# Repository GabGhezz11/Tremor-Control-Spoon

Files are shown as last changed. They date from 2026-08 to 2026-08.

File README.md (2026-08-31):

# Description

An electronic Tremor Control Spoon designed to compensate involuntary hand
tremors in Parkinson's disease patients during meals, developed as part of the
Biodesign course at Università Campus Bio-Medico di Roma in 2023 by a team of 10 students.

---

## Overview

This project focused on the design and development of an electronically
stabilized spoon to assist individuals with Parkinson's disease by compensating
tremors during meal consumption, promoting greater independence and comfort in
daily life. The work was developed in collaboration with a team of colleagues,
with my contribution made remotely while based in Vienna.

The device integrates mechanical, electronic, and control system design:

- **Sensing**: an IMU sensor (MPU-6050) for real-time motion tracking
  (acceleration and angular velocity)
- **Control**: an ATMega328-MUR microcontroller processes sensor data through a
  complementary filter to estimate roll and pitch angles
- **Actuation**: dual servo motors compensate roll and pitch tremors in real
  time, with compensation limited to ±30° on both axes to preserve natural
  eating motion

## Repository Structure

- `firmware/` — Arduino/C firmware implementing the sense-plan-act control loop
  - `TCS_control.ino` — main Arduino sketch
  - `Functions.c` — control and filtering functions
  - `Variables.h` — shared variable/constant definitions
- `electronics/` — PCB design and documentation (Eagle CAD)
  - `scheda_progetto_ver_4.2.sch` — schematic
  - `scheda_progetto_ver_4.2.brd` — board layout
  - `BoM_ver4.2.xlsx` — bill of materials
  - `scheda_progetto_ver_4` — project/design documentation
- `cad/` — Mechanical design files (Solid Edge/STEP) for the handle, motor
  case, and spoon tool
  - `.step Files/` — final STEP files, importable in any CAD software
  - `Drafts/` — intermediate/working Solid Edge design iterations
- `data-analysis/` — MATLAB scripts used to extract tremor frequency and
  acceleration/angular velocity ranges from a reference Parkinsonian tremor
  dataset, informing sensor and motor specifications

## Design Highlights

**Mechanical**: modeled in Solid Edge and based on anthropometric hand data
from adult users, optimized for usability, compactness, and dishwasher-safe
cleaning. Made of polypropylene (biocompatible, heat-resistant, dishwasher-safe)
with silicon caps for the removable USB/charging ports.

**Electronics**: sensing, control, and power supply modules integrated onto a
single miniaturized PCB (57 x 31 mm, a 10% area reduction from the original
demo stripboard), powered by a 2S1P LiPo battery (800 mAh, 7.4 V), with voltage
regulation and USB communication circuits.

**Firmware**: a complementary filter combines accelerometer and gyroscope data
to estimate roll and pitch angles, driving the servos to counteract tremor in
real time while allowing intentional tilting (e.g., to scoop food).

## Personal Contribution - Matlab Data Analysis

The analysis focused on two tremor-related tasks from the reference dataset:

- **Kinetic tremor (task AS316)**: analyzed to extract the acceleration and
  angular velocity ranges during a spoon-eating-like motion.
- **Postural tremor (task AS315)**: analyzed to identify the maximum and
  dominant frequencies of the Parkinsonian tremor signal.

### Scripts

| Script | Purpose |
|---|---|
| `Ranges_acc_v.mlx` | Computes the acceleration and angular velocity **ranges** (kinetic tremor, all 3 subjects, all 3 sensor locations) |
| `Dominant_freq_subj1.mlx` | Computes the **dominant frequency** of acc/gyro signals for Subject 1 (postural tremor) |
| `Dominant_freq_subj2.mlx` | Computes the **dominant frequency** of acc/gyro signals for Subject 2 (postural tremor) |
| `Dominant_freq_subj3.mlx` | Computes the **dominant frequency** of acc/gyro signals for Subject 3 (postural tremor) |
| `Dominant_freq_global.mlx` | Aggregates the dominant-frequency results of all subjects/locations and returns the global maximum |
| `Max_freq_subj1.mlx` | Computes the **maximum frequency** (95% PSD energy threshold) for Subject 1 (postural tremor) |
| `Max_freq_subj2.mlx` | Computes the **maximum frequency** (95% PSD energy threshold) for Subject 2 (postural tremor) |
| `Max_freq_subj3.mlx` | Computes the **maximum frequency** (95% PSD energy threshold) for Subject 3 (postural tremor) |
| `Max_freq_global.mlx` | Aggregates the maximum-frequency results of all subjects/locations and returns the global maximum |
| `createFit.m` | Auto-generated helper (MATLAB Distribution Fitter) used to fit a probability distribution to the angular velocity data — required by `Ranges_acc_v.mlx` |

### Methodology

**1. Signal preprocessing**
- Raw 3-axis accelerometer and gyroscope data are extracted from the dataset (`Subj{i}.off.taskASxxx.<sensor_location>.acc/.gyro`).
- A 4th-order Butterworth **high-pass filter** (cut-off 1 Hz), applied with `filtfilt` (zero-phase), removes gravity/motion bias while preserving tremor content.
- The 3-axis signals are combined into a single magnitude signal via the Euclidean norm (vector module).

**2. Frequency-domain analysis (postural tremor)**
- The **Power Spectral Density (PSD)** of the filtered signal is estimated with `periodogram`.
- **Dominant frequency**: frequency corresponding to the PSD peak.
- **Maximum frequency**: frequency below which 95% of the cumulative PSD energy is contained (computed via `trapz` on the PSD curve).
- Both metrics are computed per subject, per sensor location (index, thumb, metacarpus), and per signal type (acceleration, angular velocity), then aggregated across subjects to obtain the **global maximum/dominant frequency**, used to define the minimum IMU sampling rate (Nyquist criterion).

**3. Amplitude analysis (kinetic tremor)**
- Acceleration and angular velocity magnitudes are pooled across all subjects and sensor locations.
- A **kernel density estimate** (`ksdensity`, positive support) is computed for both signals.
- The upper bound of the working range is defined as the value below which 95% of the cumulative probability density falls; the range is then obtained by mirroring this value onto the negative axis (assuming symmetric bidirectional motion).
- The result is cross-checked against the 95th percentile/quantile of the raw pooled data (`quantile`, `prctile`) as a validation step.
- `createFit.m` is used to verify that the angular velocity distribution is **not normal**, justifying the use of the empirical (KDE-based) approach instead of a parametric one.

### Outputs used for hardware design
- **Acceleration range** → used to select the IMU accelerometer full-scale range.
- **Angular velocity range** → used to select the IMU gyroscope full-scale range.
- **Global maximum/dominant frequency** → used to define the minimum IMU sampling rate (via Nyquist criterion) and to size the servo motor bandwidth/response requirements.

Results informed the electronic design directly: a maximum signal frequency of 42 Hz and dominant frequency of 12.3 Hz were used to set the IMU sampling rate
(respecting the Nyquist theorem), while the acceleration range (±1.32 g) and angular velocity range (±4.91 rad/s) informed the sensor configuration.

## Key Results

- Compensates roll and pitch within ±30° on both axes
- Total weight: 133.4 g (spoon: 81 g)
- Overall length: 200 mm, comparable to a standard spoon
- Production cost: €69.28 (under the €100 target)
- Self-evaluation score: 34/40 across washability, safety, ergonomics and marketability criteria

## How to Use This Repository

- To review the firmware logic, see `firmware/TCS_control.ino`
- To inspect the PCB design, open the Eagle files (`.sch`/`.brd`) in `electronics/`
- To view the mechanical design, open the `.step` files inside `cad/.step Files/`
- To reproduce the tremor data analysis, open the MATLAB scripts in `data-analysis/`

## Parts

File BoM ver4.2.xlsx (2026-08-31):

Quantity | Value | Package | Order code | Manufacturer | Manuf. Code | Availability | Price (from) | Description
2 | 4,7uF_16V | TAN-A | 2333019 | KYOCERA AVX | TAJA475M016RNJ | 3195 | 0.094 | KYOCERA AVX - TAJA475M016RNJ - Condensatore al tantalio SMT, 4.7 µF, 16 V, 1206 [3216 metrico], ± 20%, 4 ohm, A
5 | 1uF | C0603 | 3340859 | KYOCERA AVX | 0603YC105KAT4A | 11449 | 0.034 | KYOCERA AVX - 0603YC105KAT4A - Condensatore ceramico multistrato SMD, 1 µF, 16 V, 0603 [1608 metrico], ± 10%, X7R
5 | 0.1 uF | C0603 | 2904649 | KEMET | C0603C104K3RECTU | 1830 | 0.028 | KEMET - C0603C104K3RECTU - Condensatore ceramico multistrato SMD, ESD, 0.1 µF, 25 V, 0603 [1608 metrico], ± 10%, X7R
1 | 0.01 uF | C0603 | 2456107 | MURATA | GRM1885C1H103JA01D | 29047 | 0.08 | MURATA - GRM1885C1H103JA01D - CON. 0.01µF, 50V, 5%, C0G/NP0, 0603
1 | 2200 pF | C0603 | 2534028 | WURTH ELEKTRONIK | 885012206061 | 1965 | 0.0103 | WURTH ELEKTRONIK - 885012206061 - Condensatore ceramico multistrato SMD, 2200 pF, 25 V, 0603 [1608 metrico], ± 10%, X7R, WCAP-CSGP
1 | SS1P3L | DO220AAL | 2889242 | VISHAY | SS1P3L-M3/84A | 2550 | 0.108 | VISHAY - SS1P3L-M3/84A - Raddrizzatore Schottky, 30 V, 1.5 A, singolo, DO-220AA, 2 Pin, 450 mV
1 | MFFSMF050 | 0603-1608X90N | 1717227 | BOURNS | MF-FSMF050X-2 | 7337 | 0.336 | BOURNS - MF-FSMF050X-2 - Fusibile ripristinabile PPTC, 0603 (1608 metrico), MF-FSMF, 6 VDC, 500 mA, 1 A, 0.1 s
1 | FT232RL | SSOP28 | 895-FT232RL (Mouser) | FTDI | FT232RL-REEL | 32097 | 4.46 | CI di interfaccia USB USB to Serial UART Enhanced IC SSOP-28
1 | LM1117IMPX-5.0 | LINEAR_SOT223 | 926-LM1117IMPX50NOPB (Mouser) | TEXAS INSTRUMENTS | LM1117IMPX-5.0/NOPB | 19786 | 1.26 | Regolatori di tensione LDO 800mA LDO Linear Reg
1 | 328P-MUR | VQFN32 | 2425125 | MICROCHIP | ATMEGA328P-MUR | 45330 | 2.44 | MICROCHIP - ATMEGA328P-MUR - MCU a 8 bit, bassa potenza, alte prestazioni, AVR ATmega Family ATmega328 Series Microcontrollers
1 | MCP73213T-A6AI_MF | SON50P300X300X100-11N | 579-MCP73213TA6AIMF (Mouser) | MICROCHIP | MCP73213T-A6AI/MF | 1546 | 2.24 | Gestione batterie OVP BATTERY CHARGER DUAL CELL
1 | 694106105102 | CONN3_06105102_WRE | 2472147 | WURTH ELEKTRONIK | 694106105102 | 272 | 1.08 | WURTH ELEKTRONIK - 694106105102 - Connettore di alimentazione DC, femmina, 5 A, 2 mm, montaggio superficiale (SMT)
1 | 67503-1020 | 675031020 | 1125348 | MOLEX | 67503-1020... | 7498 | 0.773 | MOLEX - 67503-1020... - Connettore USB, mini USB tipo B, USB 2.0, femmina, 5 Vie, montaggio superficiale (SMT)
1 |  | 1X02 | 3398291 | AMP - TE CONNECTIVITY | 171826-2 | 7110 | 0.178 | AMP - TE CONNECTIVITY - 171826-2 - Connettore a strip maschio, R/A, filo-scheda, 2.5 mm, 1 File, 2 Contatti
1 |  | 2X03 | 3049596 | MOLEX | 87911-0611 | 471 | 0.507 | MOLEX - 87911-0611 - Connettore a strip maschio, scheda a scheda, 2.54 mm, 2 File, 6 Contatti
2 | Green | CHIPLED_0805 | 2099239 | KINGBRIGHT | KPT-2012SGC | 15562 | 0.0824 | KINGBRIGHT - KPT-2012SGC - LED, bassa potenza, verde, SMD, 0805 [2012 metrico], 20 mA, 2.2 V, 568 nm
2 | 4.7 KΩ | R0603 | 3495312 | YAGEO | AC0603JR-074K7L | 3289 | 0.0028 | YAGEO - AC0603JR-074K7L - Resistore a chip SMD, 4.7 kohm, ± 5%, 100 mW, 0603 [1608 metrico], film spesso
5 | 1K | R0603 | 1770133 | BOURNS | CAY16-102J4LF | 22350 | 0.0176 | BOURNS - CAY16-102J4LF - Resistore di rete fisso, 1 kohm, Isolato, 4 Resistors, 1206 [3216 metrico], Convessi, ± 5%
1 | 3K | R0603 | 2908368 | BOURNS | CR0603-JW-302ELF | 76925 | 0.0018 | BOURNS - CR0603-JW-302ELF - Resistore a chip SMD, 3 kohm, ± 5%, 100 mW, 0603 [1608 metrico], film spesso, per scopi generici
1 | RESET | SMD_157SW | 653-B3U-1000P (Mouser) | OMRON ELECTRONICS INC. | B3U-1000P | 45797 | 0.94 | Interruttore tattile SPST-NO Ad azionamento dall'alto A montaggio superficiale
1 | MFS201N-16-Z | MFS201N-16-Z_NDC | 2854845 | NIDEC COMPONENTS | MFS201N-16-Z | 14 | 1.3 | NIDEC COMPONENTS - MFS201N-16-Z - Interruttore a slitta, superminiaturizzato, DPDT, On-On, foro passante (THT), MFS, 1 A, 125 V
1 | MPU-6050 | QFN50P400X400X95-24N | 410-MPU-6050 (Mouser) | TDK INVENSENSE | MPU-6050 | 21433 | 7.94 | TDK INVENSENSE - MPU-6050 - Modulo MEMS, serie MotionTracking, giroscopio/accelerometro triassiale, ±16g, 2,375V-3,46V, QFN-24
1 | 16MHz | RESONATOR | 81-CSTNE16M0VH3L000R (Mouser) | MURATA | CSTNE16M0VH3L000R0 | 60201 | 0.344 | Risonatori 16.0 MHZ 15PF

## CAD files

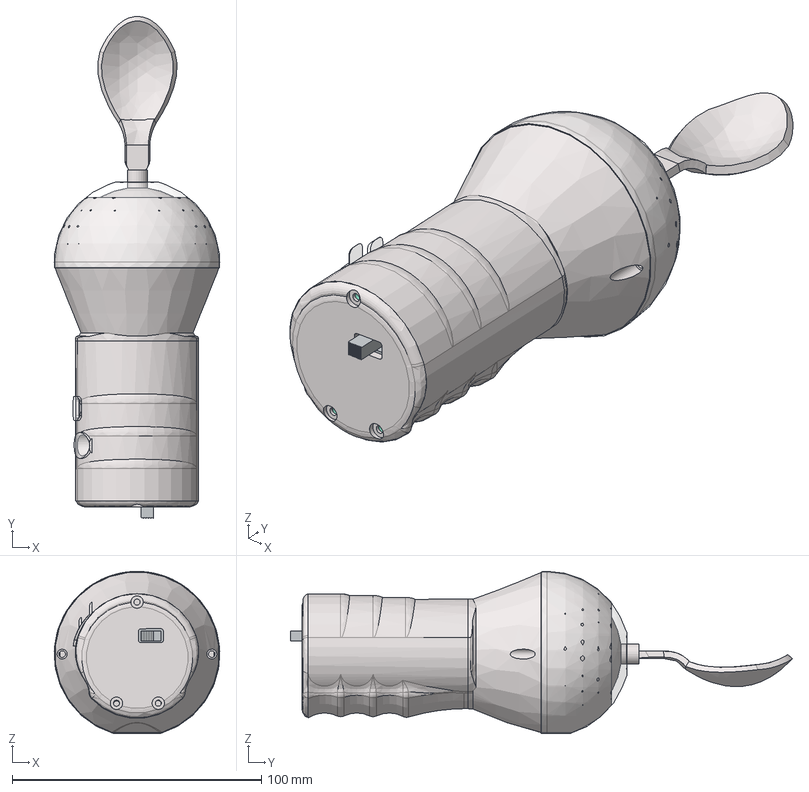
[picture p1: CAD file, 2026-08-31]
Spoon_Asm.stp
66.4 x 201.3 x 65.1 mm
HandleA
Scheda
Batteria
HandleR
CaseServi
Supporto1
Supporto2
Tool
HD1370A x 2
CaseServi2
Membrana
TappoAC
TappoUSB

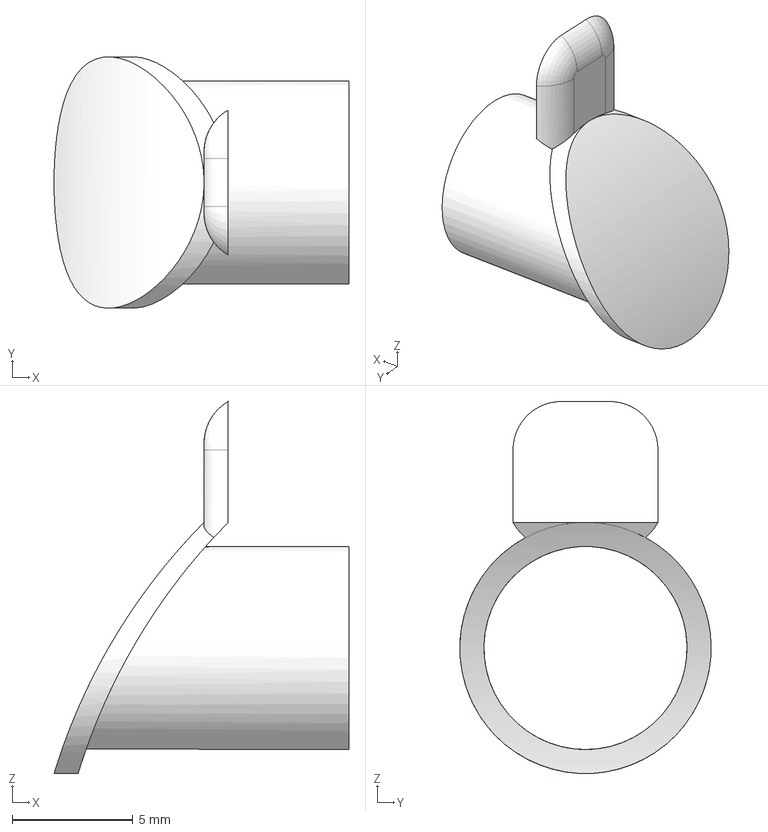
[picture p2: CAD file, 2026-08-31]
CapAC.stp
12.2 x 10.4 x 15.4 mm

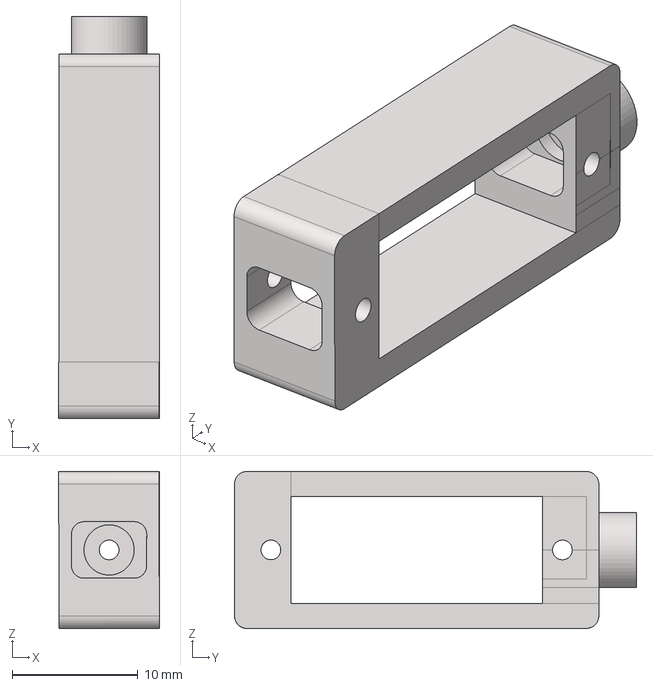
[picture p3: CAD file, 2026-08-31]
Support1.stp
8.01 x 32.0 x 12.5 mm

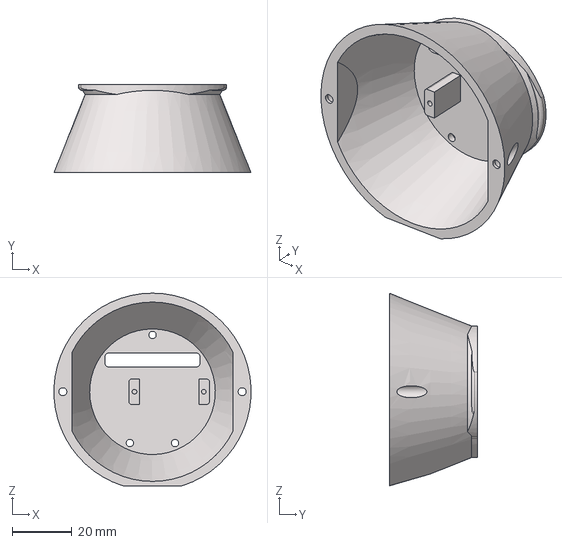
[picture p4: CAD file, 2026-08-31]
CaseServos.stp
65.9 x 29.5 x 64.5 mm

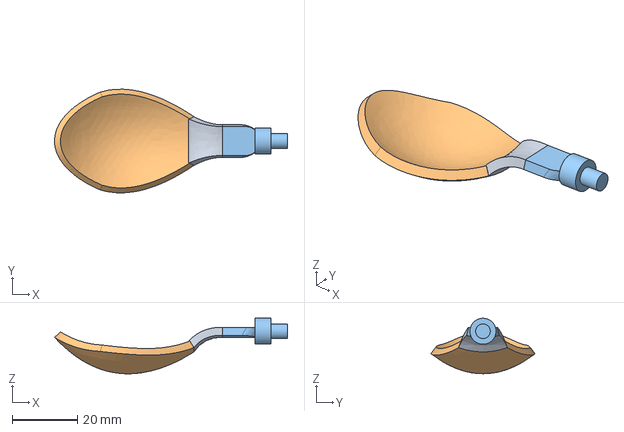
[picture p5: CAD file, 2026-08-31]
Tool.stp
71.6 x 31.8 x 17.1 mm

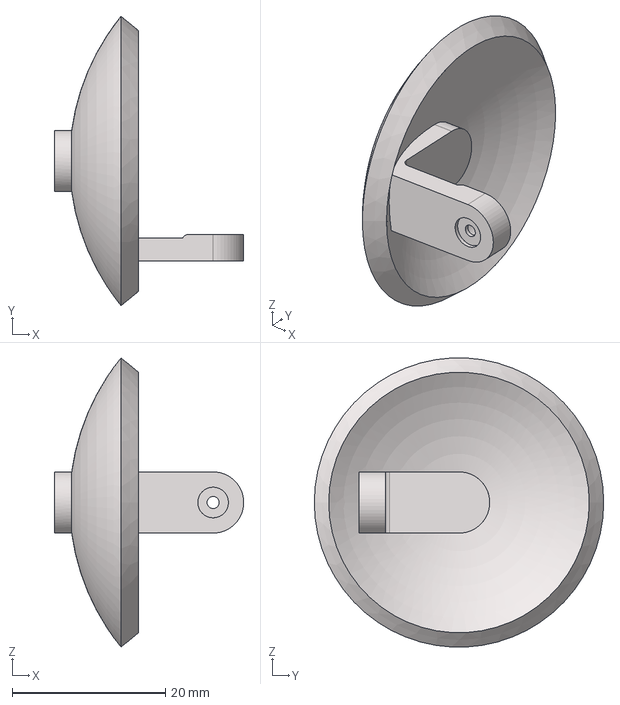
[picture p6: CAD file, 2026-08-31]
Support2.stp
24.7 x 37.8 x 37.7 mm

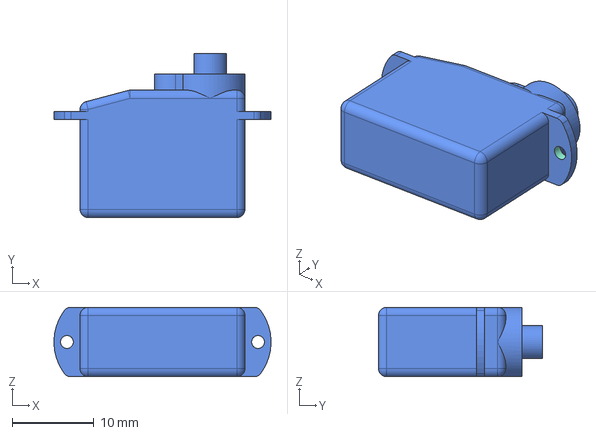
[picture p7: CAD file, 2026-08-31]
HD1370A.stp
26.6 x 20.1 x 8.50 mm

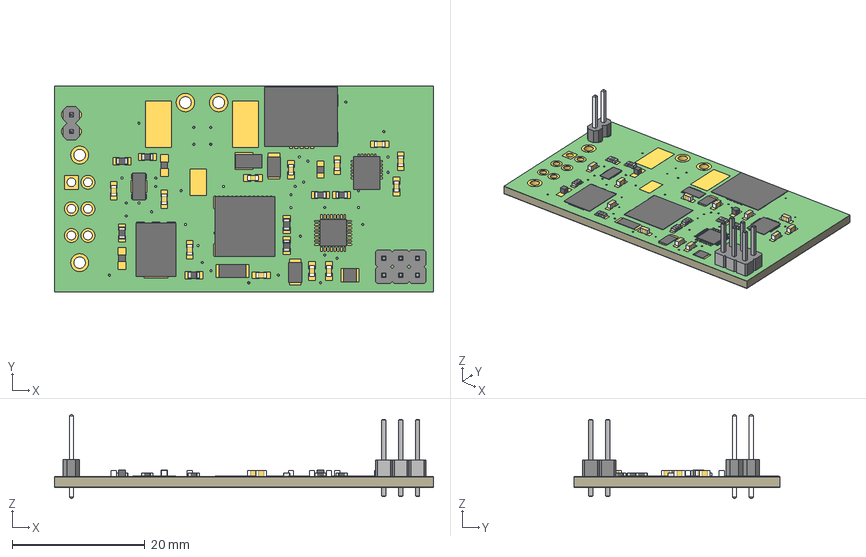
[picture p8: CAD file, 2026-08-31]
PCBFusion.step
57.0 x 31.0 x 12.6 mm
Scheda
1-copper
16-copper
1-soldermask
16-soldermask
0603-1608X90N
VQFN32
TAN-A x 2
USB-MINI-B_2
RESONATOR
DO220AAL
LINEAR_SOT223
SSOP28
SON50P300X300X100-11N
QFN50P400X400X95-24N
CHIPLED_0805 x 2
SMD_157SW
1X02
2X03
C0603 x 12
R0603 x 8

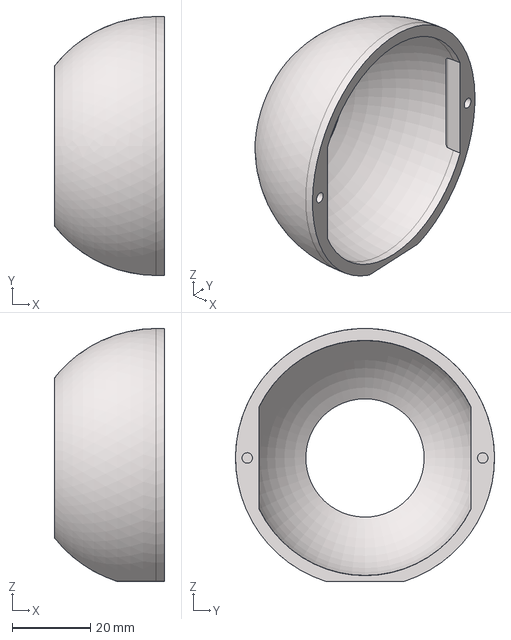
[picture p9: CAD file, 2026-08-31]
CaseServos2.stp
28.1 x 66.0 x 64.5 mm

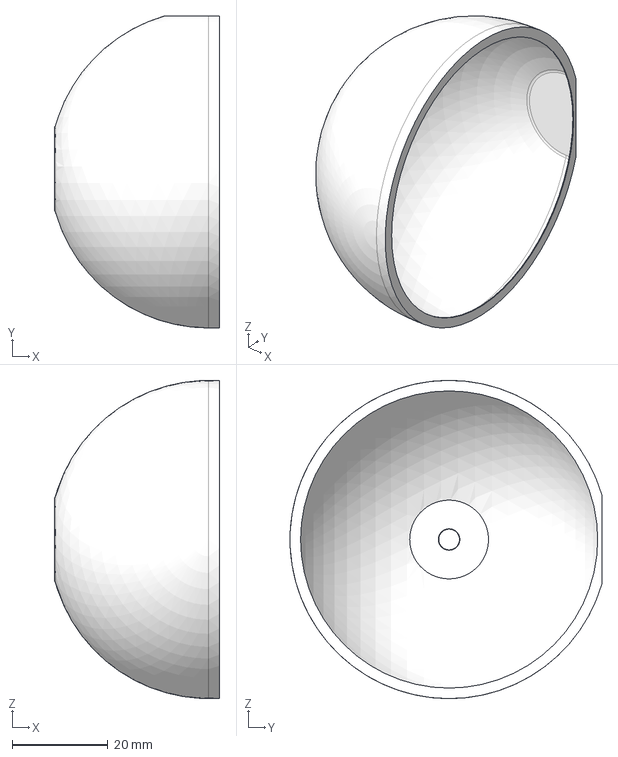
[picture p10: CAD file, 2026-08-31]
Film.stp
34.5 x 65.1 x 66.4 mm

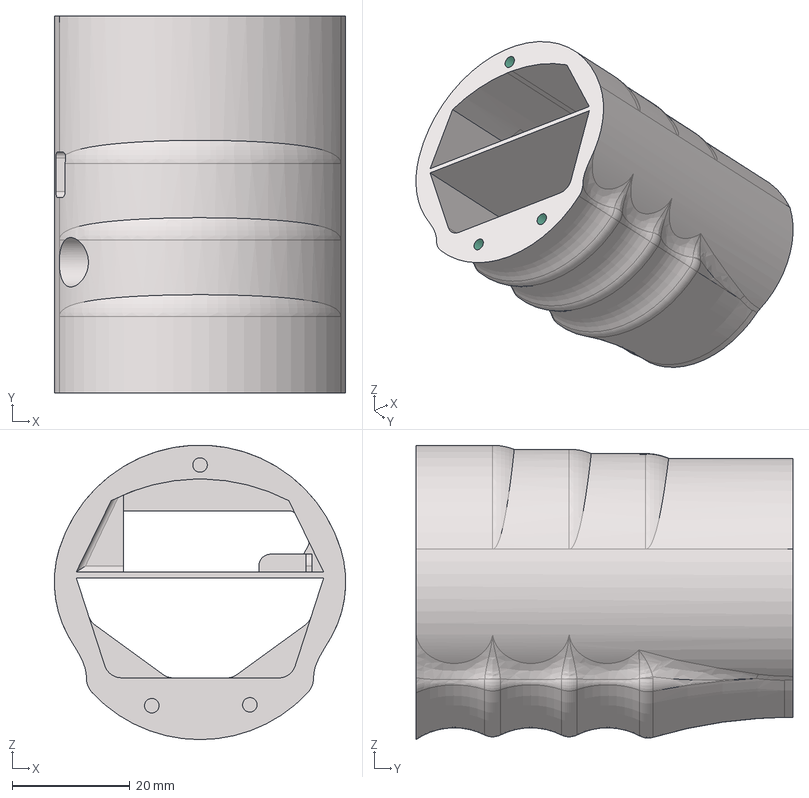
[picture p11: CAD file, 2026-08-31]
HandleA.stp
49.4 x 64.0 x 50.0 mm

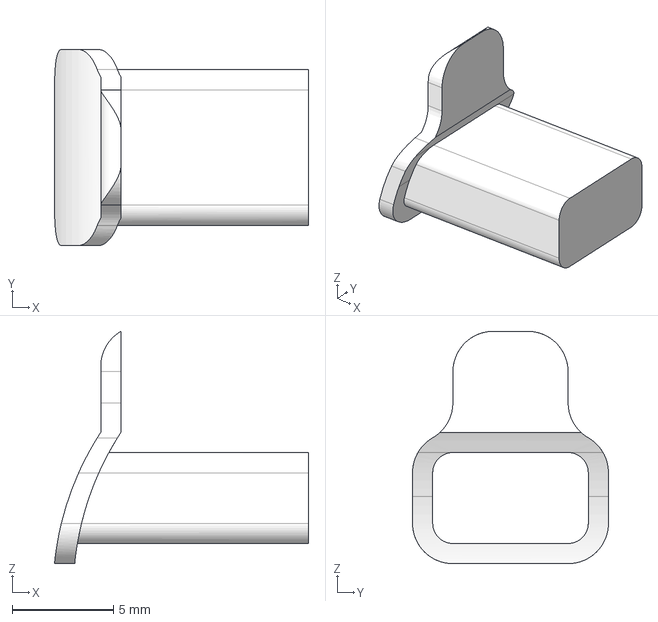
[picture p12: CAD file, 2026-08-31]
CapUSB.stp
12.6 x 9.70 x 11.5 mm

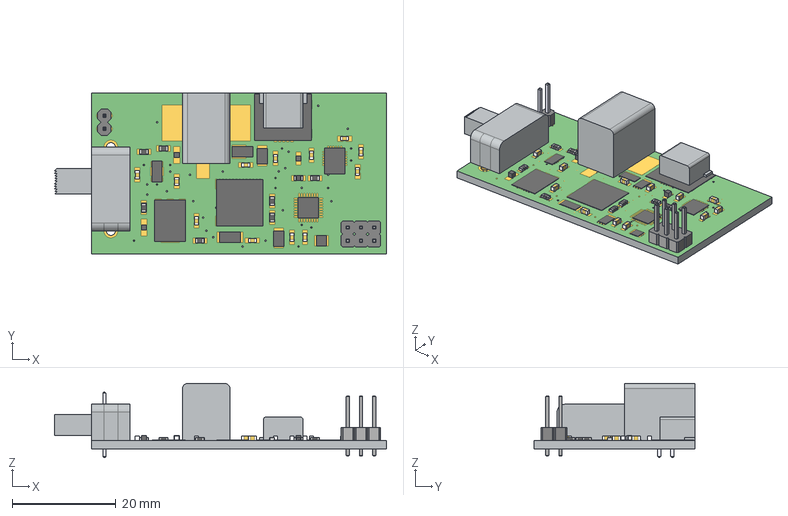
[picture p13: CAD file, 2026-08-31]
PCB.stp
64.1 x 31.0 x 14.3 mm

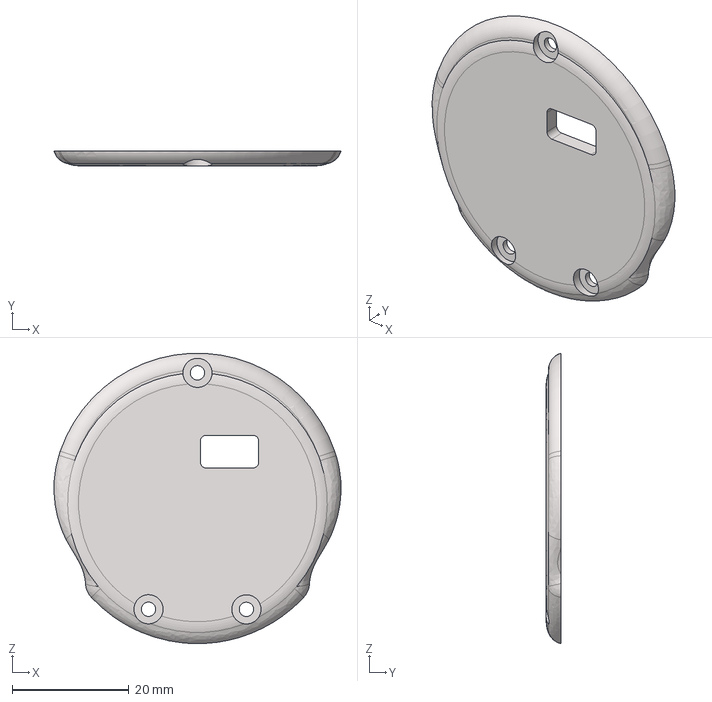
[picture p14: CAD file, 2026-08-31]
HandleR.stp
49.2 x 2.50 x 49.7 mm

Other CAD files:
Battery.stp

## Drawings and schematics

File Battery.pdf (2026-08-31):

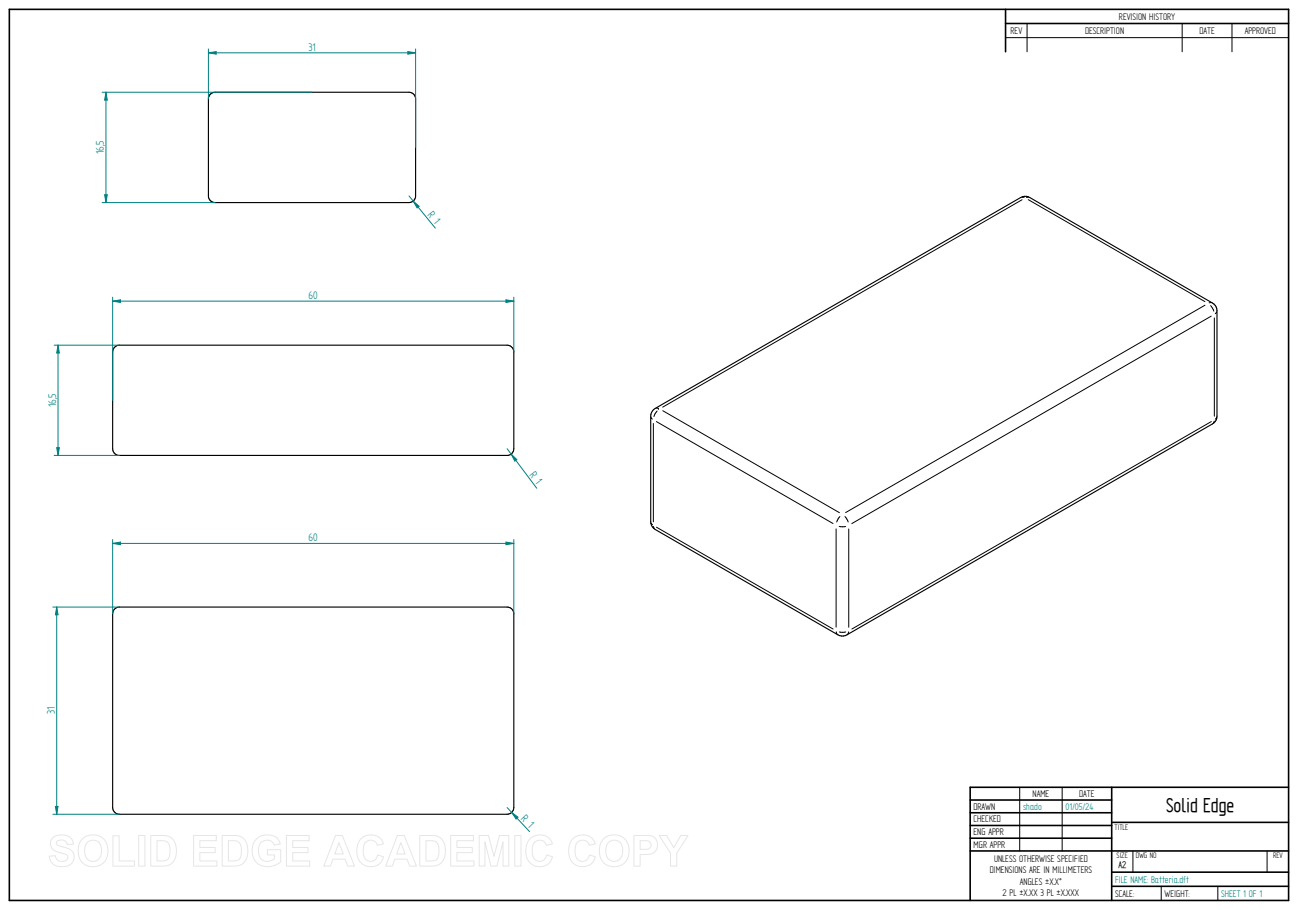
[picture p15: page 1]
TITLE; SCALE:; WEIGHT:; SHEET 1 OF 1

31 | REVISION HISTORY

REV | DESCRIPTION | DATE | APPROVED

NAME | DATE | Solid Edge

DRAWN | shado | 01/05/24
CHECKED
ENG APPR
MGR APPR
UNLESS OTHERWISE SPECIFIED DIMENSIONS ARE IN MILLIMETERS ANGLES ±X.X° 2 PL ±X.XX 3 PL ±X.XXX | SIZE A2 | DWG NO | REV

FILE NAME: Batteria.dft

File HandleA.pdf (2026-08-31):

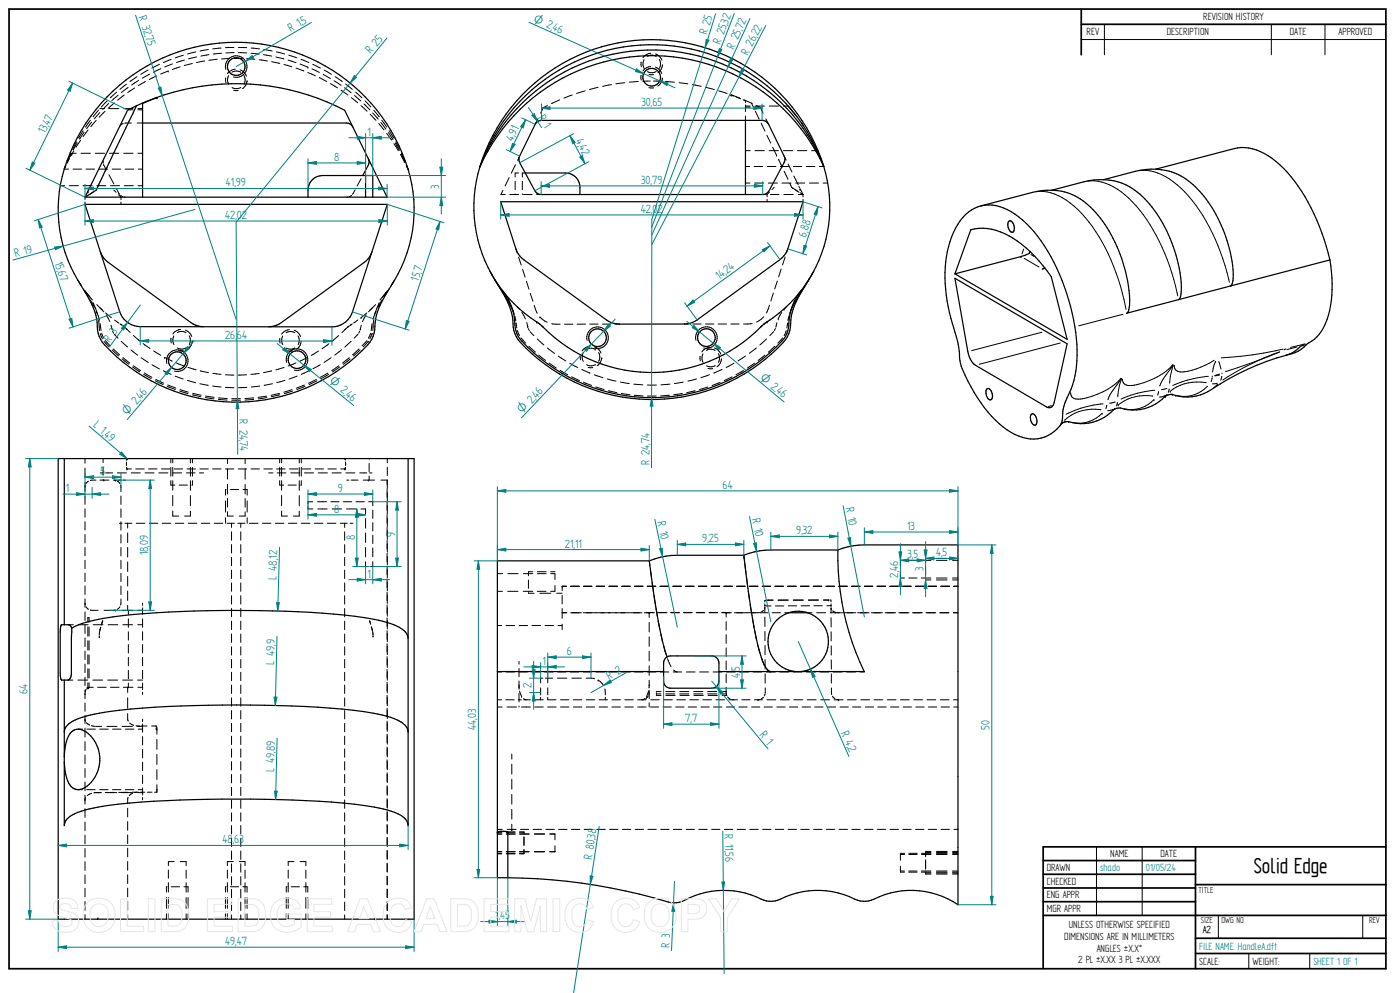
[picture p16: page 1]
ENG APPR; TITLE; SCALE:; WEIGHT:; SHEET 1 OF 1

REVISION HISTORY

REV | DESCRIPTION | DATE | APPROVED

NAME | DATE | Solid Edge

DRAWN | shado | 01/05/24
CHECKED

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

FILE NAME: HandleA.dft

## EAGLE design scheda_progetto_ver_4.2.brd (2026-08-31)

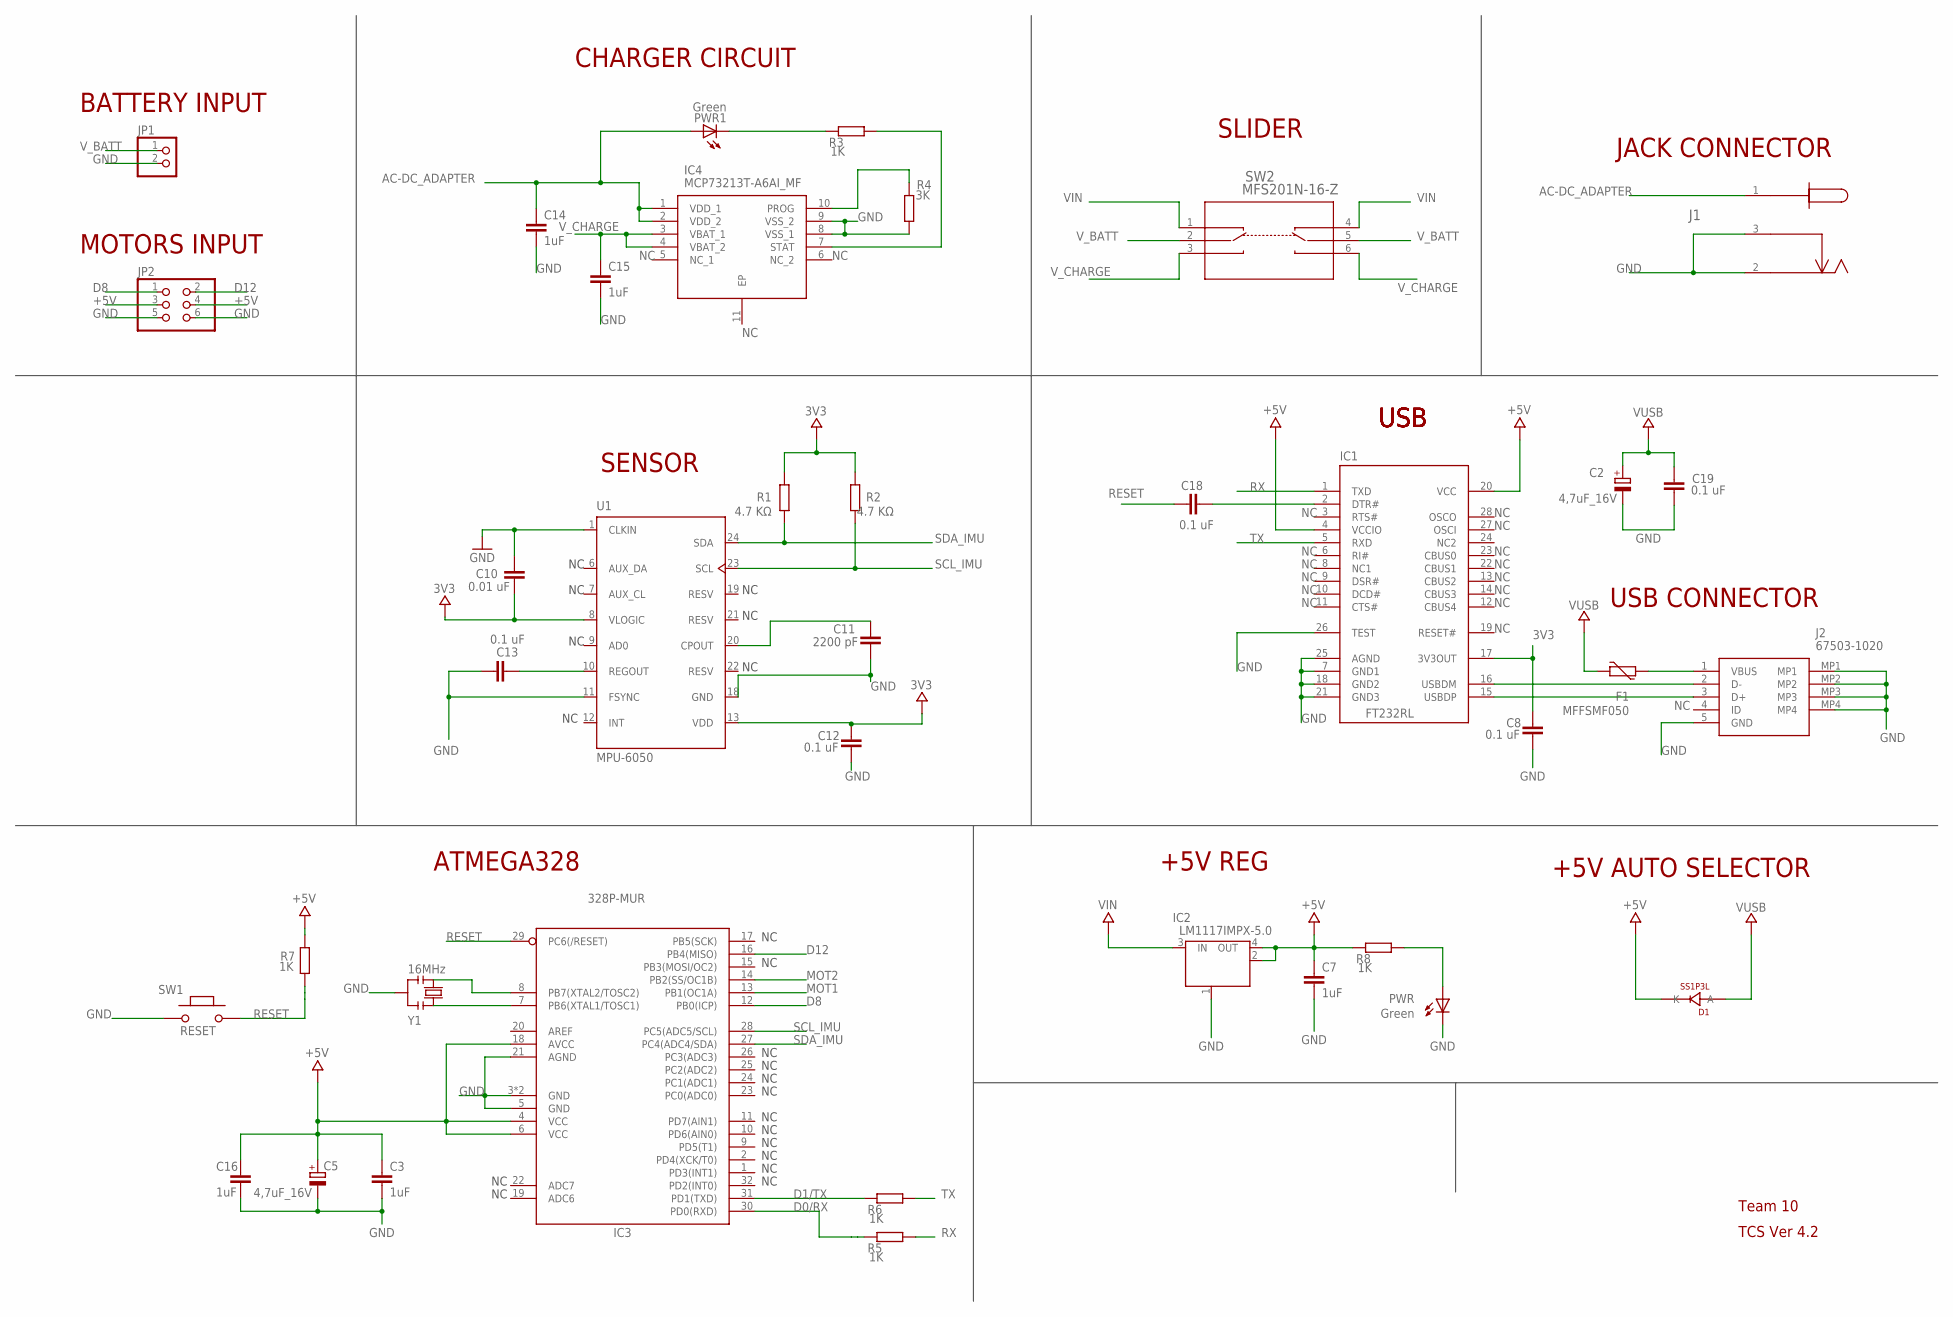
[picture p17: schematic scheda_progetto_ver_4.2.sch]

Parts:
C2, C5: 4,7uF_16V; TAN-A; MPN TAJA475M016RNJ
C3, C7, C14, C15, C16: 1uF; C0603; MPN 0603YC105KAT4A
C8, C12, C13, C18, C19: 0.1 uF; C0603; MPN C0603C104K3RECTU
C10: 0.01 uF; C0603; MPN GRM1885C1H103JA01D
C11: 2200 pF; C0603; MPN 885012206061
D1: SS1P3L; DO220AAL; MPN SS1P3L-M3/84A
F1: MFFSMF050; 0603-1608X90N; MPN MF-FSMF050X-2
IC1: FT232RL; SSOP28
IC2: LM1117IMPX-5.0; LINEAR_SOT223
IC3: 328P-MUR; VQFN32; MPN ATMEGA328P-MUR
IC4: MCP73213T-A6AI_MF; SON50P300X300X100-11N
J1: 694106105102; CONN3_06105102_WRE; MPN 694106105102
J2: 67503-1020; 675031020; MPN 67503-1020...
JP1: PINHD-1X2; 1X02; MPN 171826-2
JP2: PINHD-2X3; 2X03; MPN 87911-0611
PWR, PWR1: Green; CHIPLED_0805; MPN KPT-2012SGC
R1, R2: 4.7 KΩ; R0603; MPN AC0603JR-074K7L
R3, R5, R6, R7, R8: 1K; R0603; MPN CAY16-102J4LF
R4: 3K; R0603; MPN CR0603-JW-302ELF
SW1: RESET; SMD_157SW; MPN R13-24AL-05-BB
SW2: MFS201N-16-Z; MFS201N-16-Z_NDC; MPN MFS201N-16-Z
U1: MPU-6050; QFN50P400X400X95-24N; MPN MPU-6050
Y1: 16MHz; RESONATOR

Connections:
3V3: C8.2, C10.1, C12.2, IC1.17 (3V3OUT), R1.2, R2.2, U1.8 (VLOGIC), U1.13 (VDD)
+5V: C3.1, C5.1 (+), C7.1, C16.1, D1.P$1 (K), IC1.4 (VCCIO), IC1.20 (VCC), IC2.2 (OUT), IC2.4 (OUT), IC3.4 (VCC), IC3.6 (VCC), IC3.18 (AVCC), JP2.3, JP2.4, R7.2, R8.1
AC-DC_ADAPTER: C14.1, IC4.1 (VDD_1), IC4.2 (VDD_2), J1.1, PWR1.A
D0/RX: IC3.30 (PD0(RXD)), R5.1
D1/TX: IC3.31 (PD1(TXD)), R6.1
D8: IC3.12 (PB0(ICP)), JP2.1
D12: IC3.16 (PB4(MISO)), JP2.2
GND: C2.2 (-), C3.2, C5.2 (-), C7.2, C8.1, C10.2, C11.1, C12.1, C13.2, C14.2, C15.2, C16.2, C19.1, IC1.7 (GND1), IC1.18 (GND2), IC1.21 (GND3), IC1.25 (AGND), IC1.26 (TEST), IC2.1 (GND/ADJ), IC3.3 (GND), IC3.5 (GND), IC3.21 (AGND), IC3.33 (GND), IC4.8 (VSS_1), IC4.9 (VSS_2), J1.2, J1.3, J2.5 (GND), J2.MP1, J2.MP2, J2.MP3, J2.MP4, JP1.2, JP2.5, JP2.6, PWR.C, R4.2, SW1.1, U1.1 (CLKIN), U1.11 (FSYNC), U1.18 (GND), Y1.2
MOT1: IC3.13 (PB1(OC1A))
MOT2: IC3.14 (PB2(SS/OC1B))
unnamed: IC3.8 (PB7(XTAL2/TOSC2)), Y1.3
unnamed: IC3.7 (PB6(XTAL1/TOSC1)), Y1.1
unnamed: PWR.A, R8.2
unnamed: C18.1, IC1.2 (DTR#)
unnamed: IC1.15 (USBDP), J2.3 (D+)
unnamed: IC1.16 (USBDM), J2.2 (D-)
unnamed: C11.2, U1.20 (CPOUT)
unnamed: IC4.10 (PROG), R4.1
unnamed: PWR1.C, R3.1
unnamed: IC4.7 (STAT), R3.2
unnamed: C13.1, U1.10 (REGOUT)
unnamed: F1.2, J2.1 (VBUS)
RESET: C18.2, IC3.29 (PC6(/RESET)), R7.1, SW1.2
RX: IC1.1 (TXD), R5.2
SCL_IMU: IC3.28 (PC5(ADC5/SCL)), R2.1, U1.23 (SCL)
SDA_IMU: IC3.27 (PC4(ADC4/SDA)), R1.1, U1.24 (SDA)
TX: IC1.5 (RXD), R6.2
VIN: IC2.3 (IN), SW2.1, SW2.4
VUSB: C2.1 (+), C19.2, D1.P$2 (A), F1.1
V_BATT: JP1.1, SW2.2, SW2.5
V_CHARGE: C15.1, IC4.3 (VBAT_1), IC4.4 (VBAT_2), SW2.3, SW2.6

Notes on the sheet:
SENSOR
BATTERY INPUT
MOTORS INPUT
CHARGER CIRCUIT
JACK CONNECTOR
SLIDER
USB
USB CONNECTOR
+5V REG
+5V AUTO SELECTOR
Team 10
TCS Ver 4.2
ATMEGA328

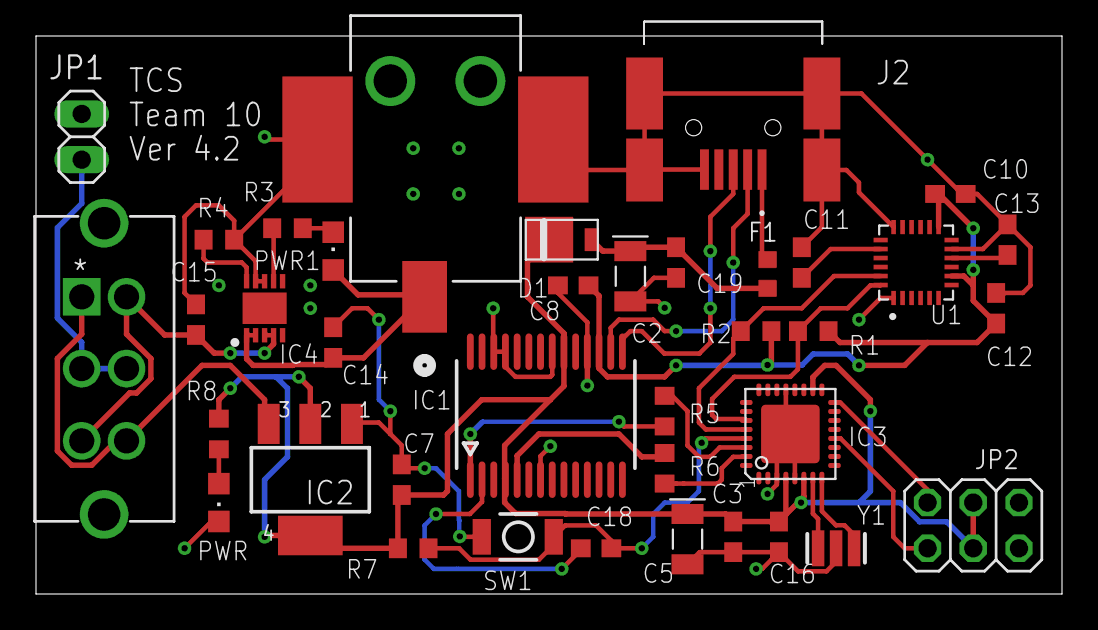
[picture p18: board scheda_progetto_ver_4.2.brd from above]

Board: 2 copper layers, 57.0 x 31.0 mm, 38 parts (0 on the bottom side), 29 nets.

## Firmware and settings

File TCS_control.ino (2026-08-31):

#include "Functions.c"
#include <Wire.h>

// Global variables
const int MPU = 0x68; // MPU6050 I2C address (pag 45 datasheet)
float acc_X, acc_Y, acc_Z; // acceleration
float gyro_X, gyro_Y, gyro_Z, gyro_XOffset, gyro_YOffset, gyro_ZOffset, gyro_X_cal, gyro_Y_cal, gyro_Z_cal; // angular velocity before and after calibration and offset
float phi = 0; // angle x axis (ROLL)
float theta = 0; // angle y axis (PITCH)
float phi_acc, theta_acc, phi_prec, theta_prec; // variables for the implementation of the complementary filter
float square_sum1;
float rad_to_deg = 180 / 3.141592654; // to convert from rad to deg
float fs = 99.5; // sampling frequency
float T = 1.0 / fs; // sampling period

void setup() {

  pinMode(motor1,OUTPUT);
  pinMode(motor2,OUTPUT);

  Serial.begin(2000000); // serial initialization
  init_MPU(); // MPU6050 initialization
  
  position90Deg(); // motors at 90°
  
  calibration(); // sensor calibration

  // Interrupt Setup
  TCCR1A = 0; // set entire TCCR1A register to 0
  TCCR1B = 0; // set entire TCCR1B register to 0
  TCCR1B |= (1 << WGM12); // CTC mode
  TCCR1B |= (1 << CS12) | (1 << CS10); // prescaler 1024
  TCNT1  = 0; // Initialize counter value to 0
  OCR1A = 156; // set OCR1A Register to 156
  TIMSK1 |= (1 << OCIE1A); // Set interrupt on OCR1A

  interrupts(); // Enable Interrupt

}

void loop() {

}

ISR(TIMER1_COMPA_vect) { // ISR associated to timer 1 through COMPA register
  
  interrupts();
  
  readFrom_MPU(); // read from sensor

  noInterrupts(); // disable interrupts

  // Subtraction of the offset
  gyro_X_cal = gyro_X - gyro_XOffset;
  gyro_Y_cal = gyro_Y - gyro_YOffset;
  gyro_Z_cal = gyro_Z - gyro_ZOffset;

  //Complementary Filter
  phi_prec = phi;
  theta_prec = theta;
  square_sum1 = sqrt((acc_Y * acc_Y) + (acc_Z * acc_Z));
  phi_acc = atan2(acc_Y, acc_Z);
  theta_acc = atan2(-acc_X, square_sum1);

  // values of coefficient found from literature
  phi = 0.04 * phi_acc * rad_to_deg + 0.96 * (gyro_X_cal * T + phi_prec);
  theta = 0.04 * theta_acc * rad_to_deg + 0.96 * (gyro_Y_cal * T + theta_prec);

  // Rotation of the motors with limit of +/-30°
  if (theta >= 30 && phi >= 30) {
    // do nothing
  }
  else if (theta >= 30) {
    MP1 = stoppedMotor();
    MP2 = rotationParameters(90 + phi_prec, 90 + phi);
    // Servo commands
    rotateMotors(MP1, MP2);
  }
  else if (phi >= 30) {
    MP1 = rotationParameters(90 + theta_prec, 90 + theta);
    MP2 = stoppedMotor();
    // Servo commands
    rotateMotors(MP1, MP2);
  }
  else if (theta <= -30 && phi <= -30) {
    // do nothing
  }
  else if (theta <= -30) {
    MP1 = stoppedMotor();
    MP2 = rotationParameters(90 + phi_prec, 90 + phi);
    // Servo commands
    rotateMotors(MP1, MP2);
  }
  else if (phi <= -30) {
    MP1 = rotationParameters(90 + theta_prec, 90 + theta);
    MP2 = stoppedMotor();
    // Servo commands
    rotateMotors(MP1, MP2);
  }
  else {
    MP1 = rotationParameters(90 + theta_prec, 90 + theta);
    MP2 = rotationParameters(90 + phi_prec, 90 + phi);
    // Servo commands
    rotateMotors(MP1, MP2);
  }

  interrupts(); // enable interrupts
}

// ---- Sensor initialization ---- 
void init_MPU() {
  Wire.begin(); // communication inizialization
  Wire.setClock(400000); // I2C frequency 400 kHz

  // Reset
  Wire.beginTransmission(MPU); // beginning of communication with MPU6050 // MPU=0x68
  Wire.write(0x6B); // call to register 6B
  Wire.write(0b1000000); // reset (DEVICE_RESET)
  Wire.endTransmission(true); // end of transmission
  delay(100);
  Wire.beginTransmission(MPU); // beginning of communication with MPU6050 // MPU=0x68
  Wire.write(0x68); // call to register 68
  Wire.write(0b0000111); // reset of gyroscope, accelerometer and temperature sensor (GYRO_RESET, ACCEL_RESET, TEMP_RESET)
  Wire.endTransmission(true); // end of transmission
  delay(100);
  
  // Configuration full-scale range accelerometer
  Wire.beginTransmission(MPU);
  Wire.write(0x1C); // call to register ACCEL_CONFIG  (1C hex)
  Wire.write(0b00000000); // set range +/-2g
  
  Wire.endTransmission(true);
  // Configuration full-scale range gyroscope
  Wire.beginTransmission(MPU);
  Wire.write(0x1B); // call to register GYRO_CONFIG (1B hex)
  Wire.write(0b00010000); // Set range +/-500°/s

  Wire.endTransmission(true);
  delay(20);
}

// ---- Acquisition from axes X,Y,Z of MPU6050 ----
void readFrom_MPU() {
  Wire.beginTransmission(MPU);
  Wire.write(0x3B); // start reading from register 0x3B (ACCEL_XOUT_H) to get data from the accelerometers 
  Wire.endTransmission(false);
  Wire.requestFrom(MPU, 6, true); // reading of the 6 registers, since the data from 1 axis is placed on 2 registers (16 bytes) (ACCEL_XOUT_H, ACCEL_XIN_H)
  while (Wire.available() < 6);
  // sensitivity: 2^(16)/2^2
  acc_X = (Wire.read() << 8 | Wire.read()) / 16384.0; // acceleration X axis 
  acc_Y = (Wire.read() << 8 | Wire.read()) / 16384.0; // acceleration Y axis 
  acc_Z = (Wire.read() << 8 | Wire.read()) / 16384.0; // acceleration Z axis

  Wire.beginTransmission(MPU);
  Wire.write(0x43); // start reading from register 0x43 (GYRO_XOUT_H) to get data from the gyroscopes
  Wire.endTransmission(false);
  Wire.requestFrom(MPU, 6, true); // reading of the 6 registers, since the data from 1 axis is placed on 2 registers (16 bytes) (GYRO_XOUT_H, GYRO_XIN_H)
  // sensitivity: 2^(16)/(2*500)
  while (Wire.available() < 6);
  gyro_X = (Wire.read() << 8 | Wire.read()) / 65.5; // angular velocity X axis
  gyro_Y = (Wire.read() << 8 | Wire.read()) / 65.5; // angular velocity Y axis
  gyro_Z = (Wire.read() << 8 | Wire.read()) / 65.5; // angular velocity Z axis

}

// ---- Gyroscopes calibration ----
void calibration(){
  for (int i = 0; i < 1000; i++) { //take 1000 measures
    readFrom_MPU(); // read from sensor

    gyro_XOffset += gyro_X;
    gyro_YOffset += gyro_Y;
    gyro_ZOffset += gyro_Z;
  }

  // computation of the mean
  gyro_XOffset /= 1000;
  gyro_YOffset /= 1000;
  gyro_ZOffset /= 1000;
}

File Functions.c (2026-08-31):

#include <Arduino.h>
#include "Variables.h"

MotorParameters MP1, MP2;
unsigned int time_high_diff; // difference between the two time_high

// ---- Rotation of the motors ----
void rotateMotors(MotorParameters MP1, MotorParameters MP2){

	unsigned int time_low1 = period1 - MP1.time_high; 
  unsigned int time_low2 = period1 - MP2.time_high; 
	int i = 0; // variable to count the impulses
	
	// If the number of impulses to be given in input to the second motor is greater
  if (MP1.nImpulse < MP2.nImpulse) {

    while (i < MP1.nImpulse) {
      digitalWrite(motor1, HIGH);
      digitalWrite(motor2, HIGH);
      
      // If the time high to be given in input to the second motor is greater than or equal to the one of the first
      if (MP1.time_high <= MP2.time_high) {
        delayMicroseconds(MP1.time_high);
        digitalWrite(motor1, LOW);
        time_high_diff = MP2.time_high - MP1.time_high;
        delayMicroseconds(time_high_diff);
        digitalWrite(motor2, LOW);
        delayMicroseconds(time_low2);
        delay(period2);
        i++;
      }
      
      // If the time high to be given in input to the first motor is greater
      else {
        delayMicroseconds(MP2.time_high);
        digitalWrite(motor2, LOW);
        time_high_diff = MP1.time_high - MP2.time_high;
        delayMicroseconds(time_high_diff);
        digitalWrite(motor1, LOW);
        delayMicroseconds(time_low1);
        delay(period2);
        i++;
      }
    }

    while (i >= MP1.nImpulse && i < MP2.nImpulse) {
      digitalWrite(motor2, HIGH);
      delayMicroseconds(MP2.time_high);
      digitalWrite(motor2, LOW);
      delay(period2);
      delayMicroseconds(time_low2);
      i++;
    }

  }

 // If the number of impulses to be given in input to the first motor is greater
 if (MP2.nImpulse < MP1.nImpulse) {

    while (i < MP2.nImpulse) {
      digitalWrite(motor1, HIGH);
      digitalWrite(motor2, HIGH);

      // If the time high to be given in input to the second motor is greater than or equal to the one of the first
      if (MP1.time_high <= MP2.time_high) {
        delayMicroseconds(MP1.time_high);
        digitalWrite(motor1, LOW);
        time_high_diff = MP2.time_high - MP1.time_high;
        delayMicroseconds(time_high_diff);
        digitalWrite(motor2, LOW);
        delayMicroseconds(time_low2);
        delay(period2);
        i++;
      }

      // If the time high to be given in input to the first motor is greater
      else {
        delayMicroseconds(MP2.time_high);
        digitalWrite(motor2, LOW);
        time_high_diff = MP1.time_high - MP2.time_high;
        delayMicroseconds(time_high_diff);
        digitalWrite(motor1, LOW);
        delayMicroseconds(time_low1);
        delay(period2);
        i++;
      }
    }

    while (i >= MP2.nImpulse && i < MP1.nImpulse) {
      digitalWrite(motor1, HIGH);
      delayMicroseconds(MP1.time_high);
      digitalWrite(motor1, LOW);
      delay(period2);
      delayMicroseconds(time_low1);
      i++;
    }

  }

  // If the number of impulses to be input to the first motor is equal to that of the second
  if (MP2.nImpulse == MP1.nImpulse) {

    while (i < MP2.nImpulse) { 
      digitalWrite(motor1, HIGH);
      digitalWrite(motor2, HIGH);

      // If the time high to be given in input to the second motor is greater than or equal to the one of the first
      if (MP1.time_high <= MP2.time_high) {
        delayMicroseconds(MP1.time_high);
        digitalWrite(motor1, LOW);
        time_high_diff = MP2.time_high - MP1.time_high;
        delayMicroseconds(time_high_diff);
        digitalWrite(motor2, LOW);
        delayMicroseconds(time_low2);
        delay(period2);
        i++;
      }

      // If the time high to be given in input to the first motor is greater
      else {
        delayMicroseconds(MP2.time_high);
        digitalWrite(motor2, LOW);
        time_high_diff = MP1.time_high - MP2.time_high;
        delayMicroseconds(time_high_diff); 
        digitalWrite(motor1, LOW);
        delayMicroseconds(time_low1);
        delay(period2);
        i++;
      }
    }
  }
}

// ---- Bring the motors at 90° ----
void position90Deg(){
  MotorParameters MP;
	MP.time_high = 1500; // time high for 90°
	MP.nImpulse = 9; // number of pulses to rotate for at least 90°
	rotateMotors(MP, MP);
}

// ---- Calculate the parameters for the rotation of the motors ----
MotorParameters rotationParameters(int theta0, int theta){
  MotorParameters MP;
	MP.time_high = ceil(1400-((70/9)*theta));
	MP.nImpulse = ceil((0.12*abs(theta0-theta)/60)/0.02);

  return MP;
}

// ---- Not to move the motors ----
MotorParameters stoppedMotor() {
  MotorParameters MP;
	MP.time_high = 0;
	MP.nImpulse = 0;

  return MP;
}

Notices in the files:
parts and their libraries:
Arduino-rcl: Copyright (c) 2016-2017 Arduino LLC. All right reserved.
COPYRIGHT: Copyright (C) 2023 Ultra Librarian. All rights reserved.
